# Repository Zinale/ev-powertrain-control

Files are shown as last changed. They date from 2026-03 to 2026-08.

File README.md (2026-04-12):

# MCU (Motor Control Unit) - Peacock Elettrica ⚡

This repository contains the Motor Control Unit firmware for the Polimarche Racing Team electric vehicle. It includes code for managing dual AMK inverters via CAN Bus, reading sensors via ADC with DMA, FSAE-compliant safety logic, single-pedal regenerative braking, and vehicle dynamics models in MATLAB/Simulink. The board used is the STM32 Nucleo-F756ZG.

> **Note:** This repository covers only the **MCU** and the MATLAB/Simulink vehicle dynamics models. The ECU (sensor acquisition board) has been moved to its own repository.

## Features
- ✅ **AMK Inverter Control**: Full state machine (IDLE → LV → HV → READY → RUNNING) with AMK 8.2.6 error recovery sequence and automatic retry logic.
- ✅ **Regenerative Braking**: Four-stage single-pedal regen with speed fade-out, battery power limit, and DC bus voltage derating.
- ✅ **FSAE Safety Compliance**: APPS plausibility checks (T11.8.9, T11.8.10) and MCU state machine with torque interlock.
- ✅ **ADC with DMA**: Continuous multi-channel reading (APPS1, APPS2, Steering) without CPU overhead.
- ✅ **Dual CAN Bus**: CAN1 for inverter protocol, CAN2 for vehicle telemetry (dashboard, BMS, IMU, R2D).
- ✅ **Signal Filtering**: Median + Moving Average cascade on APPS and SAS for noise rejection.
- ✅ **FreeRTOS Real-Time Architecture**: 1 kHz motor control task, 1 kHz sensor task, 10 Hz logging task.
- ✅ **Vehicle Dynamics Models**: MATLAB/Simulink models for slip control, torque vectoring, and straight-line control.

## 🔗 Repository Structure

The repository is organized into three main sections: **mcu-stm32** (STM32 firmware), **Controls** (MATLAB/Simulink models), and **Tests** (bench test infrastructure and data).

```
├── mcu-stm32/                       # STM32F756ZG firmware (main project)
│   ├── mcu-stm32.ioc                # STM32CubeMX configuration
│   └── Core/
│       ├── Inc/                     # Headers organized by subsystem
│       │   ├── Config.h             # Build modes, feature flags, parameters
│       │   ├── Communication/       # CAN bus & UART serial
│       │   ├── Drive/               # Inverter, torque control, regen, error recovery
│       │   ├── Safety/              # MCU state machine, device state, watchdog
│       │   ├── Sensors/             # ADC/DMA, APPS, steering angle
│       │   └── Tasks/               # FreeRTOS task definitions
│       └── Src/                     # Implementations (mirrors Inc/ structure)
│
├── Controls/                        # MATLAB/Simulink vehicle dynamics models
│   ├── SlipControl/                 # Traction/slip ratio control
│   ├── StraightLineControl/         # Straight-line stability
│   └── TorqueVectoring/             # Torque vectoring with 3D car model
│
├── AIPEX/                           # AMK inverter configuration files (.aipex)
│   ├── FIXED_speed/                 # Speed control mode configurations
│   ├── FREE_torque/                 # Torque control mode configurations
│   ├── Scope Templates/             # AipexPRO oscilloscope templates
│   └── Errors/                      # Error log files
│
├── Documents/                       # Datasheets, manuals, AipexPRO guides
│
├── Tests/                           # Test infrastructure & bench data
│   ├── DataCollectorSoftware/       # Python/MATLAB data logging & analysis
│   ├── ControlUnit_Nucleo_F756ZG/   # Alternative board test project
│   ├── ESP32-WIFI-BT-communication/ # Wireless telemetry via ESP32
│   ├── FeatherDataCollectorBancoMotori/ # Feather CAN data logger
│   └── FixedCan - Banco Loccioni/   # Last bench test in Speed-Control mode
│
└── Regen_Pedal_Behavior.md          # Detailed regen pedal behavior documentation
```

### MCU (Motor Control Unit)
The firmware on the STM32F756ZG manages AMK inverter control in real time:
- **Drive modules**: AMK state machine, torque control loop, error recovery, regenerative braking
- **Sensor acquisition**: DMA-based ADC reading, APPS and steering processing
- **CAN communication**: Inverter setpoints on CAN1, vehicle telemetry on CAN2
- **Safety**: MCU state machine with torque interlock, APPS plausibility, watchdog

### Controls
MATLAB/Simulink models developed to study and simulate vehicle dynamics:
- **SlipControl**: Traction/slip ratio control algorithms
- **StraightLineControl**: Straight-line torque distribution
- **TorqueVectoring**: Full torque vectoring model with 3D vehicle dynamics

### Tests
Development, bench testing, and data collection infrastructure:
- **DataCollectorSoftware**: Python CSV logger + MATLAB analysis scripts
- **ControlUnit_Nucleo_F756ZG**: Alternative MCU implementation for testing
- **ESP32-WIFI-BT-communication**: Wireless data streaming from bench
- **FixedCan - Banco Loccioni**: Last bench test configuration (Speed-Control mode, Loccioni dyno)

## 🏗️ Detailed Control Unit Structure

The control unit implementation is located in `mcu-stm32/`. The architecture follows a modular design with feature-specific subfolders. Subfolders within `Inc/` contain headers (.h), while subfolders within `Src/` provide the corresponding sources (.c).

```
└── mcu-stm32/
    ├── mcu-stm32.ioc                  # STM32CubeMX configuration file
    └── Core/
        ├── Inc/
        │   ├── Config.h               # Build modes, feature flags, all parameters
        │   ├── Communication/
        │   │   ├── Can.h              # CAN1 (inverters) + CAN2 (vehicle) TX/RX
        │   │   └── Serial.h           # DMA UART logging (UART3, UART5, UART6)
        │   ├── Drive/
        │   │   ├── Inverter.h         # AMK state machine + CAN message decode
        │   │   ├── BaseControlMotor.h # Torque control loop, rate limiting, LEDs
        │   │   ├── ErrorRecovery.h    # AMK 8.2.6 error reset state machine
        │   │   └── Regen.h            # 4-stage regenerative braking
        │   ├── Safety/
        │   │   ├── MCU_State.h        # System state machine (INIT→READY→RUNNING/ERROR)
        │   │   ├── device_state.h     # Device state tracking
        │   │   └── watchdog.h         # IWDG refresh
        │   ├── Sensors/
        │   │   ├── ADC_Manager.h      # Centralized DMA ADC handling
        │   │   ├── APPS.h             # Accelerator Pedal Position Sensors (FSAE T11.8)
        │   │   └── SAS.h              # Steering Angle Sensor with filtering
        │   └── Tasks/
        │       ├── motors_manager.h   # 1 kHz inverter control task
        │       ├── data_manager.h     # 1 kHz sensor sampling task
        │       └── data_logger.h      # 10 Hz UART/CAN2 telemetry task
        └── Src/
            ├── Communication/
            │   ├── Can.c
            │   └── Serial.c
            ├── Drive/
            │   ├── Inverter.c
            │   ├── BaseControlMotor.c
            │   ├── ErrorRecovery.c
            │   └── Regen.c
            ├── Safety/
            │   ├── MCU_State.c
            │   ├── device_state.c
            │   └── watchdog.c
            ├── Sensors/
            │   ├── ADC_Manager.c
            │   ├── APPS.c
            │   └── SAS.c
            ├── Tasks/
            │   ├── motors_manager.c
            │   ├── data_manager.c
            │   └── data_logger.c
            └── main.c
```

## 🧪 Build Modes & Testing

The project supports different build modes configured in `Config.h`. This allows testing with limited hardware availability.

### Test Mode: Single ADC (`TEST_MODE_SINGLE_ADC`)
Enable when only **ADC1 CH0 (PA0)** is available:

```c
// In Config.h — uncomment to enable:
#define TEST_MODE_SINGLE_ADC
```

**Effects:**
- Uses only 1 ADC channel instead of 3
- APPS sensor 2 is simulated (duplicates sensor 1 value)
- Sensor mismatch plausibility check **disabled** (can't verify with 1 sensor)
- Range check **disabled**
- Deadzone 30% still active for realistic pedal behavior

### Test Mode: Full (`TEST_MODE_FULL`)
Enable for bench testing with all ADC channels but relaxed safety thresholds:

```c
// In Config.h — uncomment to enable:
#define TEST_MODE_FULL
```

**Effects:**
- All 3 ADC channels active (APPS1, APPS2, Steering)
- Implausibility threshold relaxed to 20% (instead of 10%)
- Implausibility timeout extended to 500 ms (instead of 100 ms)

### Production Mode (`RELEASE_MODE`)
Comment out all test modes for full FSAE compliance:

```c
// In Config.h — comment out all test modes:
//#define TEST_MODE_SINGLE_ADC
//#define TEST_MODE_FULL
#define RELEASE_MODE
```

**Effects:**
- All 3 ADC channels active
- Full APPS plausibility check: mismatch >10% for >100 ms → shutdown
- Full range check (open/short circuit detection)
- Deadzone 30% active
- All FSAE safety rules enforced

## 🎮 Module Descriptions

### APPS (Accelerator Pedal Position Sensors)
Located in `Sensors/APPS.h` and `Sensors/APPS.c`:
- **Dual sensor reading**: Two redundant potentiometers with independent transfer functions
- **Signal filtering**: Median filter (11 samples) + Moving Average (40 samples) cascade
- **Normalization**: Converts raw ADC values to 0–100% pedal position
- **FSAE Plausibility checks**:
  - **T11.8.9**: Sensor mismatch >10% for >100 ms → motor shutdown
  - **T11.8.10**: Auto-reset when pedal returns below 5%
  - **Out-of-range detection**: Open/short circuit with ADC bounds checking

### ADC Manager
Located in `Sensors/ADC_Manager.h` and `Sensors/ADC_Manager.c`:
- **DMA circular mode**: Continuous multi-channel ADC without CPU intervention
- **Thread-safe access**: Getter functions for other modules
- **Channels**: APPS1 (PA0), APPS2 (PA1), Steering (PC3)

### Inverter Control
Located in `Drive/Inverter.h` and `Drive/Inverter.c`:
- **AMK state machine**: IDLE → LV_ACTIVE → HV_ACTIVE → READY → RUNNING
- **CAN message decoding**: Status words (SM1–SM5), speed, torque, temperatures, power
- **AMK protocol**: Control word bits for enable, DC activation, error reset

### Error Recovery
Located in `Drive/ErrorRecovery.h` and `Drive/ErrorRecovery.c`:
- **AMK 8.2.6 sequence**: `bInverterOn=0` → `bErrorReset=1` (50 ms hold) → `bErrorReset=0` (falling edge triggers reset)
- **Retry logic**: Up to 5 automatic recovery attempts with 100 ms cooldown between tries
- **Per-inverter context**: Independent recovery state for each motor node

### Base Control Motor
Located in `Drive/BaseControlMotor.h` and `Drive/BaseControlMotor.c`:
- **Dynamic torque limiting**: AMK formula based on speed and DC bus voltage (`M = P / (2π × N/60)`)
- **Rate limiting**: Smooth torque transitions (10 units per ms)
- **Status LED management**: Visual feedback for error and running states

### Regenerative Braking
Located in `Drive/Regen.h` and `Drive/Regen.c`:
- **4-stage calculation**: Pedal-dependent → speed fade-out → battery power limit → DC bus derating
- **Latch hysteresis**: Entry/exit thresholds to prevent regen chattering at low speed
- **Configurable intensity**: CONSERVATIVE / BALANCED / AGGRESSIVE modes in `Config.h`

### CAN Communication
Located in `Communication/Can.h` and `Communication/Can.c`:
- **CAN1**: Inverter protocol — setpoints TX at 1 kHz, status RX at 1 kHz
- **CAN2**: Vehicle telemetry — BMS, IMU, R2D RX; error snapshots and sensor data TX
- **Hardware**: SN65HVD230 CAN transceiver (×2)

### Serial Communication
Located in `Communication/Serial.h` and `Communication/Serial.c`:
- **DMA-based transmission**: Non-blocking TX on UART3, UART5, UART6
- **Per-channel enable**: Each UART can be independently enabled/disabled in `Config.h`
- **Mutex-protected**: Thread-safe printf-style logging from FreeRTOS tasks

## ⏱️ FreeRTOS Task Architecture

The system uses FreeRTOS with three dedicated tasks. All shared data is protected via FreeRTOS mutexes.

### Task Overview

| Task | Period  | Responsible for |
|---|---|---|
| `MotorsManagerTask` | 10 ms  | Inverter state machine, torque command, error recovery, regen |
| `DataManagerTask`  | 4 ms | ADC reading, APPS/SAS processing, sensor filtering |
| `DataLoggerTask` | 100 ms  | UART serial output and CAN2 telemetry |

### Motors Manager Task (10 ms)
The core control loop executed every 10 ms:

```c
void MotorsManagerTask(void *argument)
{
    for (;;)
    {
        // 1. Read sensor data (pedal %, steering %)
        // 2. For each inverter:
        //    a. Decode CAN status (Inverter_ProcessReceivedMessage)
        //    b. Run state machine + error recovery (Motor_ProcessInverterControl)
        //    c. If RUNNING: compute torque setpoint with regen + rate limit
        //    d. Send CAN command (Inverter_BuildCommand + Can_SendInverterCommand)
        osDelay(INVERTERS_TASK_PERIOD_MS);
    }
}
```

### Data Manager Task (4 ms)
Runs ADC acquisition and sensor processing every 1 ms:

```c
void DataManagerTask(void *argument)
{
    for (;;)
    {
        // 1. Read DMA ADC buffer (ADC_Manager_GetValues)
        // 2. Process APPS (APPS_Process) — filtering + plausibility
        // 3. Process SAS  (SAS_Process)  — filtering + normalization
        // 4. Update MCU state machine
        osDelay(1);
    }
}
```

### Data Logger Task (100 ms)
Outputs diagnostics and telemetry every 100 ms:

```c
void DataLoggerTask(void *argument)
{
    for (;;)
    {
        // 1. Log inverter data via UART (Serial_Log)
        // 2. Transmit CAN2 telemetry messages (APPS%, steering%, inverter data, errors)
        osDelay(100);
    }
}
```

## 🛠️ Commands & Installation

### MCU Control Unit (STM32)

1. **Clone the repository**:
   ```bash
   git clone https://github.com/PolimarcheRacingTeam/ev-powertrain-control.git
   ```
2. **Open the project with STM32CubeIDE**
3. **Navigate to `mcu-stm32/`** (the main firmware project)
4. **Select build mode** in `Core/Inc/Config.h` (see Build Modes section)
5. **Compile and upload** to the Nucleo-F756ZG board
6. **Monitor serial output** at 115200 baud (e.g., using Termite or PuTTY on UART3)

### AMK Inverter Configuration (AIPEX)

1. **Install AipexPRO** (refer to `Documents/AipexPRO/`)
2. **Load configuration** from `AIPEX/FREE_torque/` (torque control) or `AIPEX/FIXED_speed/` (speed control)
3. **Connect to AMK inverter** via CAN bus
4. **Use scope templates** from `AIPEX/Scope Templates/` for live monitoring

### Data Collection (Bench / Tests)

1. **Navigate to `Tests/DataCollectorSoftware/`**
2. **Run the Python logger** `csv_socket_logger.py` — streams CSV data from ESP32 over Wi-Fi
3. **Analyze data** using `analyze_test_log.m` in MATLAB

## 🔧 Hardware Configuration

### STM32F756ZG Peripherals
(see `mcu-stm32/mcu-stm32.ioc` for full CubeMX configuration)

- **ADC1**: 3-channel DMA circular mode — APPS1 (PA0), APPS2 (PA1), Steering (PC3)
- **CAN1**: Inverter communication at 1 Mbit/s (SN65HVD230 transceiver)
- **CAN2**: Vehicle telemetry at 500 kbit/s (SN65HVD230 transceiver)
- **UART3**: PC debug serial at 115200 baud (DMA TX)
- **UART5**: Data logger / ESP32 at 115200 baud (DMA TX)
- **UART6**: External device (DMA TX)
- **GPIO**: LD2 (green), LD3 (red) status LEDs; R2D signal input

### CAN Bus Hardware
- **Transceiver**: SN65HVD230 (3.3 V compatible), ×2 for CAN1 + CAN2
- **Baud Rates**: CAN1 @ 1 Mbit/s (AMK inverter), CAN2 @ 500 kbit/s (vehicle)
- **Termination**: 120 Ω at both ends of each bus

### AMK Motor & Inverter
- **Motor**: AMK DD series — 9.8 Nm nominal, 21 Nm peak, 16000 RPM max
- **Inverter**: AMK KW-R25 — CAN-based torque control
- **CAN node IDs**: Right inverter = 1 (0x184/0x284), Left inverter = 2 (0x185/0x285)

## 🏎️ FSAE Rules Compliance

### APPS Plausibility (T11.8.9)
- Dual redundant sensors with independent transfer functions
- If sensor mismatch exceeds 10% for more than 100 ms → motor power immediately cut
- Configurable in `APPS.h`:
  ```c
  #define APPS_IMPLAUSIBILITY_THRESHOLD_PERCENT   10U   // Difference threshold [%]
  #define APPS_IMPLAUSIBILITY_TIMEOUT_MS          100U  // Time before failure [ms]
  ```

### APPS Reset (T11.8.10)
- After an implausibility event, torque cannot be restored until the pedal returns below 5%
- Prevents unintended torque restoration after driver removes foot

### Out-of-Range Detection (EV.4.7)
- Each ADC channel checked for open-circuit (value too low) and short-circuit (value too high)
- Detection uses configurable ADC margin counts
- Fault triggers shutdown independently from plausibility check

## 📚 Documentation References

### Internal Documentation
- **AMK Inverter**: `Documents/` — AipexPRO guides, training materials, password info
- **Regen behavior**: `Regen_Pedal_Behavior.md` — full pedal-speed regen interaction map
- **MCU Configuration**: `mcu-stm32/mcu-stm32.ioc` — STM32CubeMX project configuration

### FSAE Rules Reference
- **Formula SAE Rules**: [FSAE Online](https://www.fsaeonline.com/)
- **T11.8.9 / T11.8.10**: APPS sensor plausibility and reset conditions
- **EV.4.7**: Accelerator pedal position sensor requirements

### External Resources

- **NUCLEO F756ZG**:  
  📄 [Pinout](https://os.mbed.com/platforms/ST-Nucleo-F756ZG/)

- **SN65HVD230 CAN Transceiver**:  
  🎞️ [Video Tutorial 1](https://youtu.be/KHNRftBa1Vc?si=2C673-Au-6wTgh2l)  
  🎞️ [Video Tutorial 2](https://www.youtube.com/watch?v=-lcrrRrKdFg)

- **STM32 ADC with DMA**:  
  🎞️ [Video Tutorial](https://www.youtube.com/watch?v=zipjCtiHYr8)  
  📄 [In-depth Guide](https://deepbluembedded.com/stm32-adc-multi-channel-scan-continuous-mode-dma-poll-examples/)

- **AMK Motor & Inverter**:  
  📄 [AipexPRO Documentation](Documents/AipexPRO/)

## 👥 Authors

- **Alessandro Zingaretti** — *Polimarche Racing Team, UNIVPM*

## 👀 Interested in Learning More?

If you have any questions, would like to discuss this project further, or are interested in potential collaboration opportunities, please feel free to connect with us:

- LinkedIn: [polimarcheracingteam](https://www.linkedin.com/company/polimarcheracingteam/posts/?feedView=all)
- Instagram: [polimarcheracingteam](https://www.instagram.com/polimarcheracingteam/)
- Email: [formulasae@sm.univpm.it](mailto:formulasae@sm.univpm.it)

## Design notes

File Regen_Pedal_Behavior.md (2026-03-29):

# Regen — Comportamento Pedale nelle varie condizioni

> Configurazione: `DEADZONE=25%`, `REGEN_THRESHOLD=25%`, `HYST=±3%`, `MODE=CONSERVATIVE (4.9 Nm max)`, `SPEED_MIN=3000 RPM`, `SPEED_CRITICAL=2000 RPM`

## Pedale fisico → `final_percent`

| Pedale fisico | `final_percent` |
|:---:|:---:|
| 0-25% | 0% (deadzone) |
| 25-100% | 0-100% (lineare) |

---

## Comportamento per condizione di velocità

### 🔴 Velocità < 2000 RPM — **Solo trazione**
Regen **impossibile** (latch forzatamente OFF).

| `final_pct` | Coppia |
|:---:|:---|
| 0% | 0 Nm (coasting) |
| 50% | +10.3 Nm |
| 100% | +20.6 Nm |

---

### 🟡 Velocità 2000-3000 RPM — **Trazione + regen solo se già attiva**
Non puoi **entrare** in regen, ma se eri già in regen (latch ON da prima) ci resti con fade-out.

| `final_pct` | Se latch OFF (trazione) | Se latch ON (regen) |
|:---:|:---|:---|
| 0% | 0 Nm (coasting) | -4.9 × k_vel Nm (fade-out) |
| 22% | +4.6 Nm | -0.6 × k_vel Nm |
| 28% | +5.8 Nm | latch OFF → +5.8 Nm |
| 100% | +20.6 Nm | — |

*k_vel = speed / 3000 (es. a 2500 RPM → k_vel = 0.83)*

---

### 🟢 Velocità > 3000 RPM — **Trazione + regen completa**
Puoi **entrare** in regen. Coppia regen al 100%.

| `final_pct` | Modo | Coppia |
|:---:|:---:|:---|
| 0% | **REGEN** | **-4.9 Nm** (100% regen conservative) |
| 12.5% | REGEN | -2.45 Nm |
| 22% | LATCH border | -0.6 Nm (regen) o +4.6 Nm (trazione) |
| 22-28% | LATCH band | Mantiene modo precedente |
| 28% | **TRACTION** | +5.8 Nm |
| 50% | TRACTION | +10.3 Nm |
| 100% | TRACTION | **+20.6 Nm** |

---

### Protezione aggiuntiva
| Condizione | Coppia |
|:---|:---:|
| speed < 10 RPM | **0 Nm** |
| speed > 16000 RPM | **0 Nm** |
| DC bus > 380V | Regen derata |
| DC bus > 395V | Regen = 0 |

---

## Schema riassuntivo completo

```
                    < 2000 RPM        2000-3000 RPM       > 3000 RPM
                 ┌──────────────┬──────────────────┬──────────────────┐
  Pedale 0%      │  0 Nm coast  │ -4.9×k Nm (se    │  -4.9 Nm         │
  (rilasciato)   │              │  già in regen)    │  REGEN PIENA     │
                 │              │ 0 Nm (se no)      │                  │
  ───────────────┼──────────────┼──────────────────┼──────────────────┤
  Pedale 22%     │  +4.6 Nm     │ dipende dal latch │ dipende dal latch│
  (latch enter)  │  trazione    │                  │                  │
  ───────────────┼──────────────┼──────────────────┼──────────────────┤
  Pedale 28%     │  +5.8 Nm     │  +5.8 Nm         │  +5.8 Nm         │
  (latch exit)   │  trazione    │  TRAZIONE         │  TRAZIONE        │
  ───────────────┼──────────────┼──────────────────┼──────────────────┤
  Pedale 100%    │  +20.6 Nm    │  +20.6 Nm        │  +20.6 Nm        │
  (pieno)        │  trazione    │  TRAZIONE         │  TRAZIONE        │
                 └──────────────┴──────────────────┴──────────────────┘
```

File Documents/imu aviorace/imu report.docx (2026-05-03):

Testing IMU Aviorace

Introduzione

Il presente documento riporta i risultati delle prove eseguite sull'Inertial Measurement Unit (IMU) installato sulla nostra vettura prodotto da Aviorace. L'obiettivo delle prove era di verificare la corretta funzionalità dell'IMU e di identificare eventuali problemi di ricezione CAN o di alimentazione.

Descrizione delle prove

Le prove sono state eseguite in due fasi:

1. Prima accensione: l'IMU è stato acceso per la prima volta con una tensione di alimentazione di 12 V e una corrente di 20 mA. In questa fase, l'IMU non ha funzionato correttamente.
2. Seconda accensione: dopo aver consultato l'ufficio tecnico di Aviorace, è stato stabilito che la corrente richiesta dall'IMU era di 120 mA. Pertanto, l'IMU è stato acceso nuovamente con una tensione di alimentazione di 12 V e una corrente di 120 mA.

IMMAGINI SETUP PROVA DA BANCO

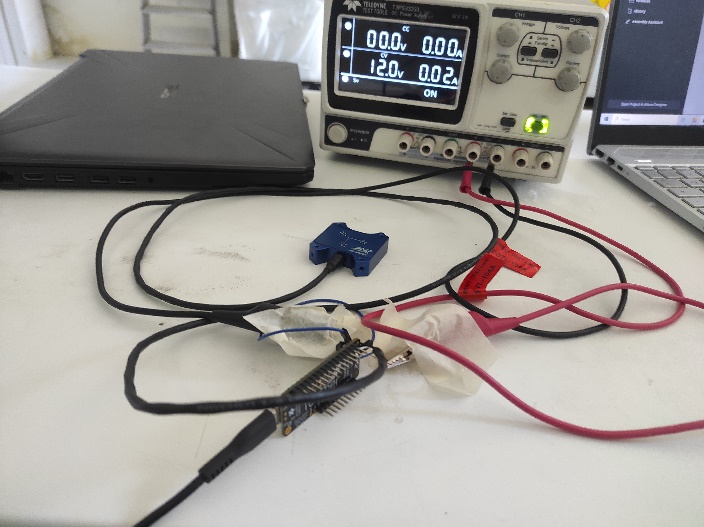
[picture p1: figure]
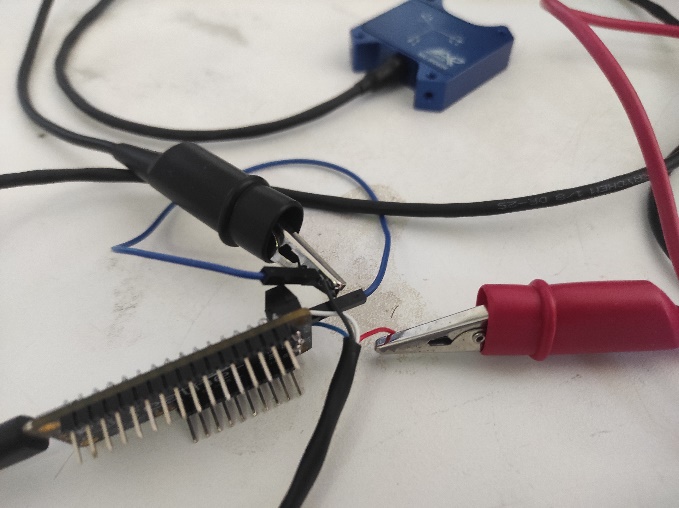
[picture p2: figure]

Risultati delle prove

I risultati delle prove sono riportati nella seguente tabella:

Parametro | Valore
Tensione di alimentazione | 12 V
Corrente assorbita | 20-30 mA
Corrente richiesta ( da inserire sul generatore) | 120 mA

Dai risultati delle prove, si evince che l'IMU richiede una corrente di 120 mA per funzionare correttamente, mentre la corrente assorbita è di 20-30 mA.

Configurazione dell'IMU

Inoltre, è stato stabilito che l'IMU può inviare valori anche senza la necessità di inviare messaggi CAN. Tuttavia, abbiamo deciso di inviare un ID CAN per impostare diversi valori.

REPROGRAM CAN ID:

Byte 0: 0x01 | DEFAULT
Byte 1: 0xAO | DEFAULT
Byte2: 0x01 | DEFAULT
Byte3: 0x02 (ACC RANGE) | 12G
Byte4:0x01 (GYRO RANGE) | DEAFULT- 250 deg/s
Byte5:0x01 (BAUD RATE) | 500kbit/s
Byte6:0x00 | CAN HI
Byte7:0x00 | CAN LO

POSITIONING CAN ID:

Byte 0: 0x01 | DEFAULT
Byte 1: 0XA3 | DEFAULT
Byte2: 0xAA | DEFAULT
Byte3: 0xAA | DEFAULT
Byte4:0xAA | DEAFULT
Byte5:0x00 | VEDI MOUNTING
Byte6: 0x01 Acc frequency 3dB | 19hz -DEFAULT
Byte 7: 0x01 Gyro frequency 3dB | 32 hz

ZERO OFFSET CAN ID:

Byte 0: 0x01 | DEFAULT
Byte 1: 0XA1 | DEFAULT
Byte2: 0xAA | DEFAULT
Byte3: 0xAA | DEFAULT
Byte4:0xAA | DEFAULT
Byte5:0xAA | DEFAULT
Byte6:0xAA | DEFAULT
Byte7:0xAA | DEFAULT

Conclusioni

In conclusione, le prove eseguite sull'IMU hanno evidenziato la necessità di una corrente di 120 mA per la sua corretta funzionalità. La configurazione dell'IMU è stata aggiornata di conseguenza. Ulteriori prove saranno eseguite per verificare la corretta ricezione dei valori dell’IMU.

Raccomandazioni

Si raccomanda di verificare regolarmente la corrente assorbita dall'IMU per garantire la sua corretta funzionalità. Inoltre, si consiglia di eseguire ulteriori prove per ottimizzare la configurazione dell'IMU e migliorare la sua precisione.

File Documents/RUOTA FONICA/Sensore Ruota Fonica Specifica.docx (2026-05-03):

Product Requirements Document

# SVH hall effect speed sensor

Issued by | Role/Department | Date
Chiara Facchini | Electronics Division Leader | 24/10/2025

# GENERAL PRODUCT DESCRIPTION

Product Description
Key Features/ Functionality | Hall-effect speed sensor, ideal for measuring the speed of bolts and tone wheels
Working conditions | Content in the phonic wheel Operating temperature: -30°C ÷ +110°C Degree of Protection: IP67 CNC-machined anodized aluminum body for excellent mechanical resistance to impacts.
Rules | No
Dimensions and Tolerances | Cfr. Rendering section
Weight | ≈ 26 g
Produzione | Aviorace SRL

# REGULATORY

Regulatory Requirements
Safety
Structural
Electrical

# DESIGN

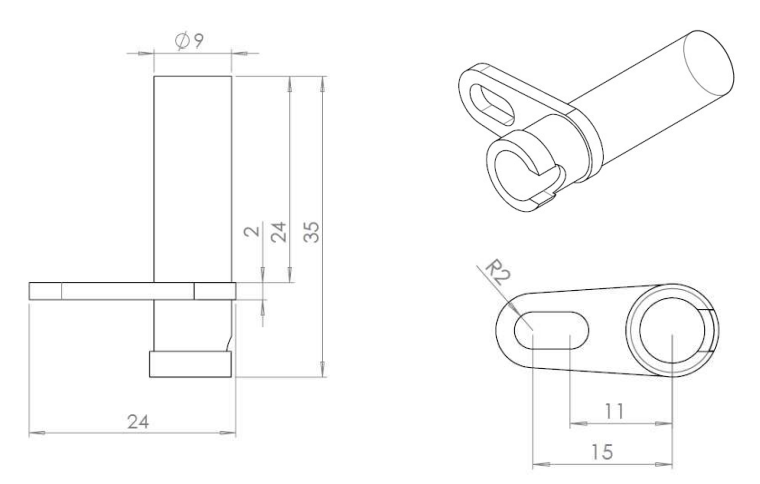
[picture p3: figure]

Renderings

# ENVIRONMENT

Operating Environment
Where in the car | Front structure
Temperature Range | -30°C ÷ +110°C

# ELECTRICAL HARDWARE AND SENSORS

Supply Voltage | 5 ÷ 18 Vdc
Supply Current | Maximum output current: 25 mA Current consumption at 12 VDC: < 20 mA
Input/Sensor Requirements | https://aviorace.com/wp-content/uploads/2021/01/SVH-rev6.pdf

# BOM

Bill of material
BOM

Financials
BOM Cost

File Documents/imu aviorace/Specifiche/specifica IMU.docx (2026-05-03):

Product Requirements Document

IMU

Issued by | Role/Department | Date
Lorenzo Meloccaro | Electronics Team Member | 01/10/2025

# GENERAL PRODUCT DESCRIPTION

Product Description
Key Features/ Functionality | The Inertial Measurement Unit (IMU) should read accelerations and angles during car’s motion sending Via CAN Bus reading of accelerometer, gyroscope and magnetometer
Software | n.a.
Other components Compatibility, Ecosystem, etc. | CanBus
Working conditions | Ip60
Rules | n.a.
Dimensions and Tolerances | 44x42x11 cm
Weight | 60 g ca
Produzione | Aviorace
Connections | Connected via CanBus to the MCU

# DESIGN

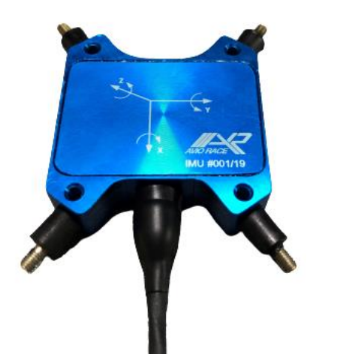
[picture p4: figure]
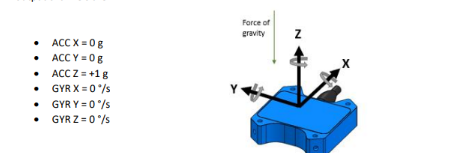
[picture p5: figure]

Renderings

# INTERFACE

Communication protocol | CanBus
Communication Input | N.a.
Communication output | CanBus
Connector | N.a.

# ELECTRICAL HARDWARE AND SENSORS

Supply Voltage | 8-16 V
Supply Current | 20 mA
Input/Sensor Requirements | N.a.
Output/Actuator Requirements | Ax,Ay,Az Gx, Gy,Gz Mx, My, Mz
OverVoltage/ OverCurrent / Short Circuit Protection on power supply | N.a.
OverVoltage/ OverCurrent / Short Circuit Protection on output | Max 50 mA

# BOM

Bill of material
BOM

Financials
BOM Cost

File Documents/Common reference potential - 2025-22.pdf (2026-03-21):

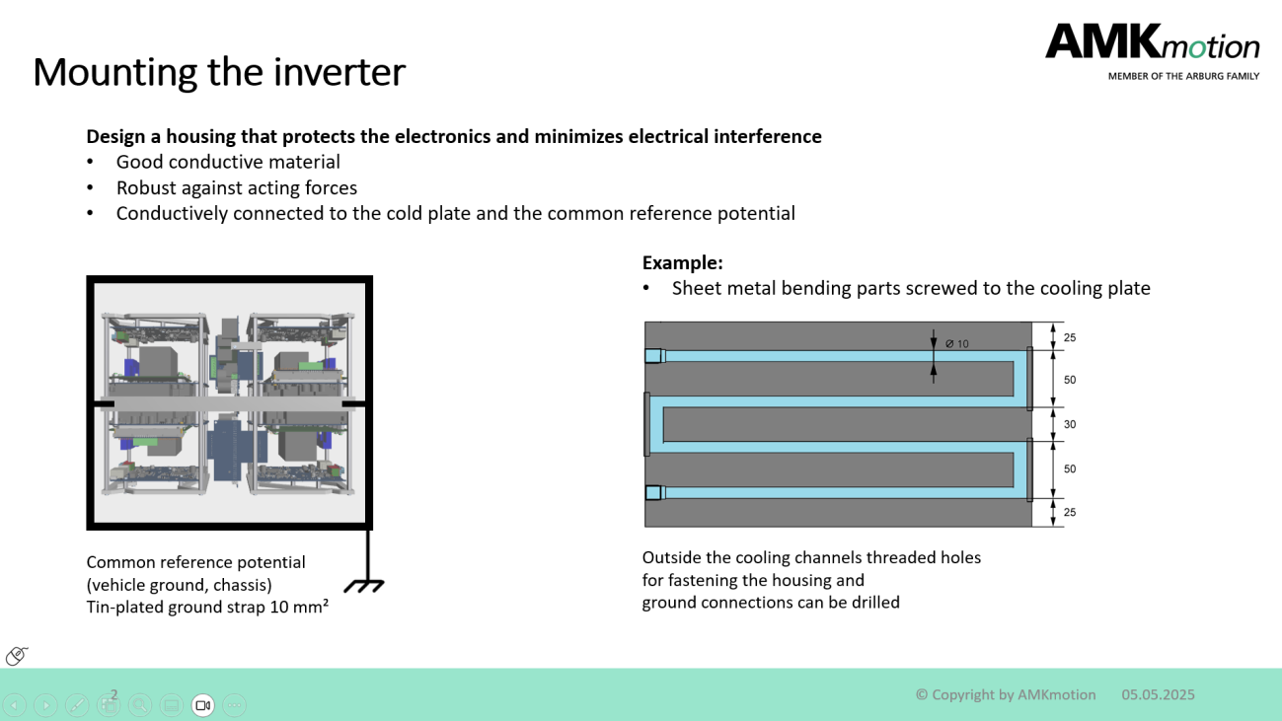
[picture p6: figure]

Common reference potential - 2025-22 | Rev:01/26.05.2025 | Seite 1 von 4
26.05.2025

Common reference potential (Shielding and Grounding)

Motor / Inverter
In the case of high-frequency interference, it is not the cross-section of the wire important, but the surface (because of skin effect).
Use a tin-plated ground strap with 10 mm²

Motor
Connect each motor separately to the common reference potential.

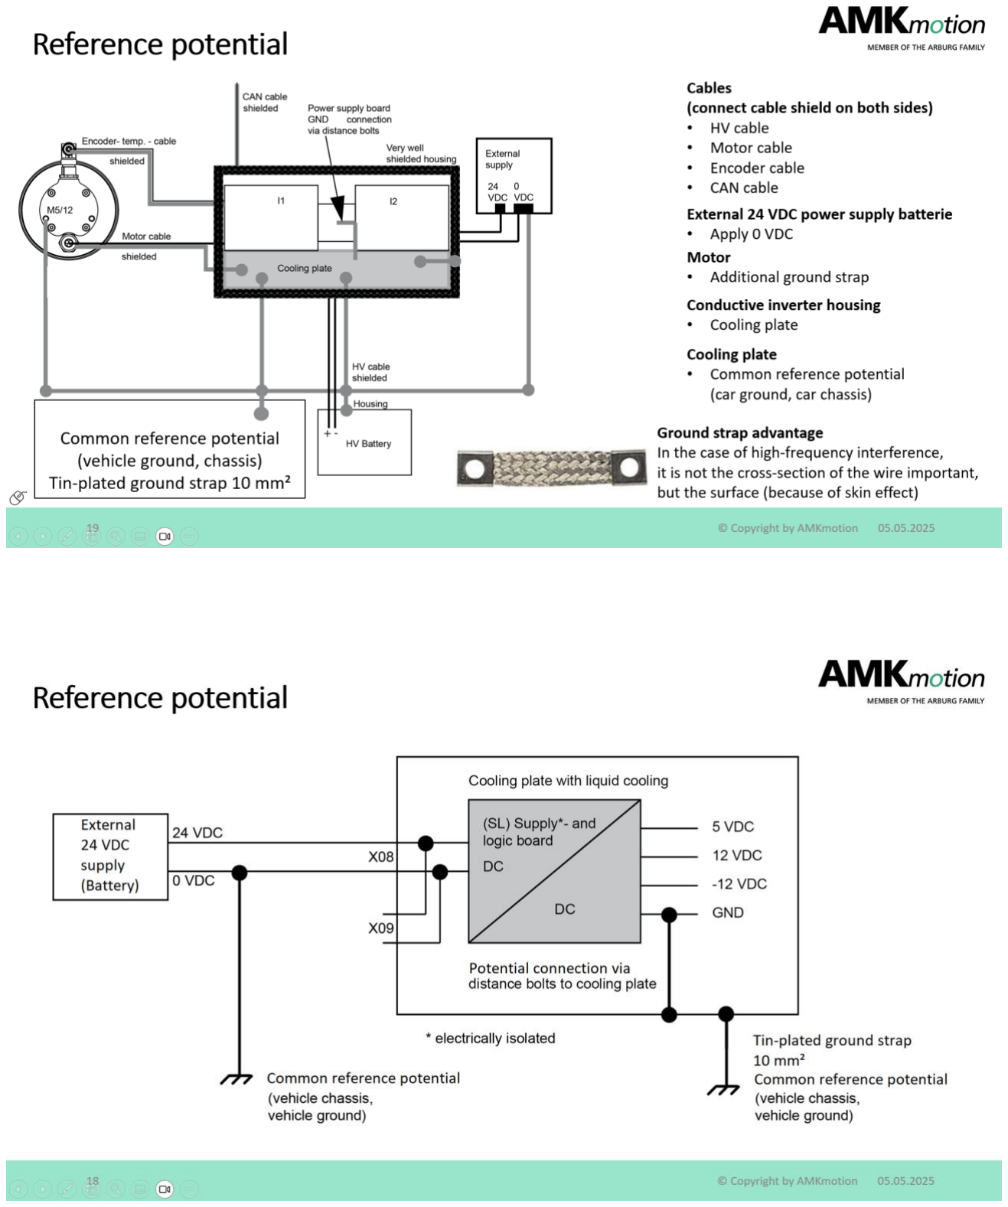
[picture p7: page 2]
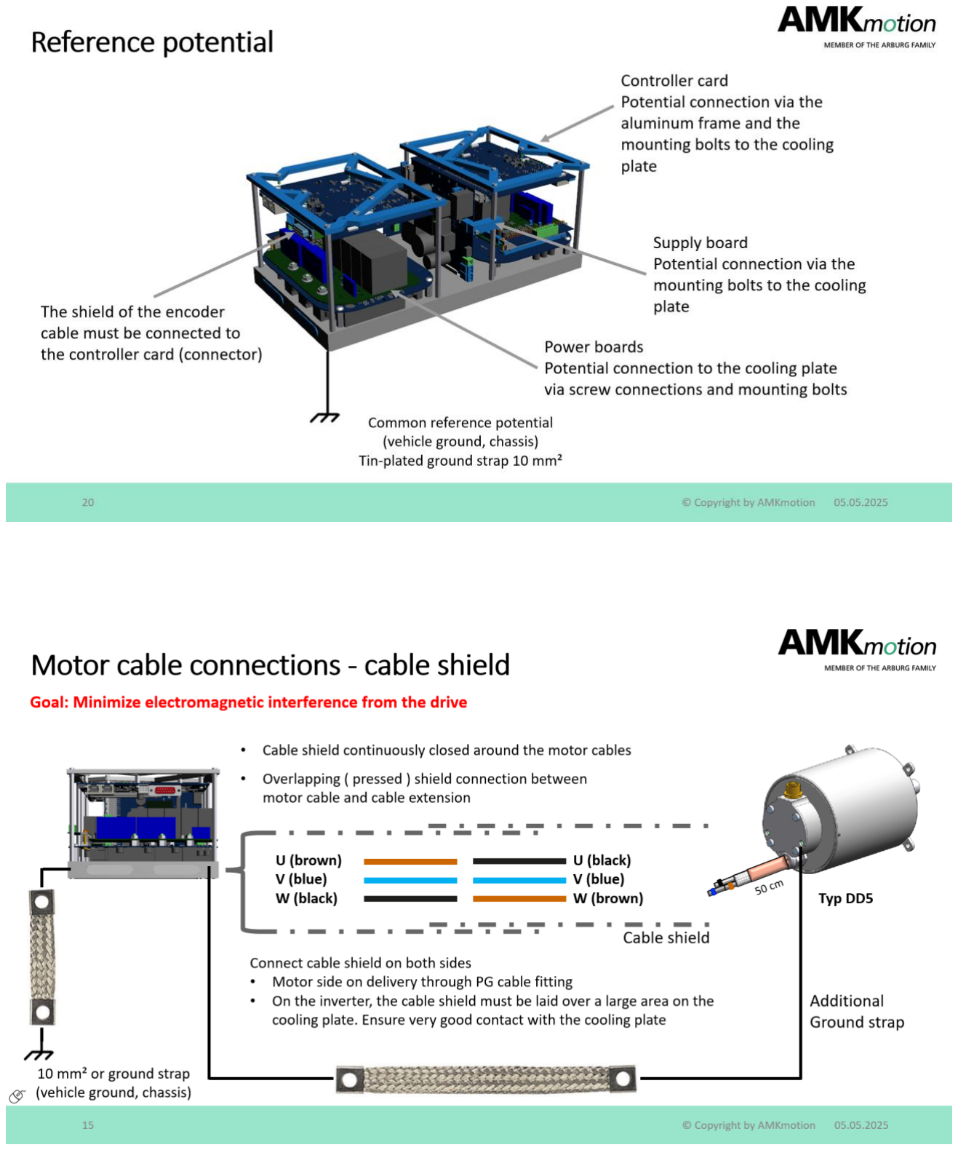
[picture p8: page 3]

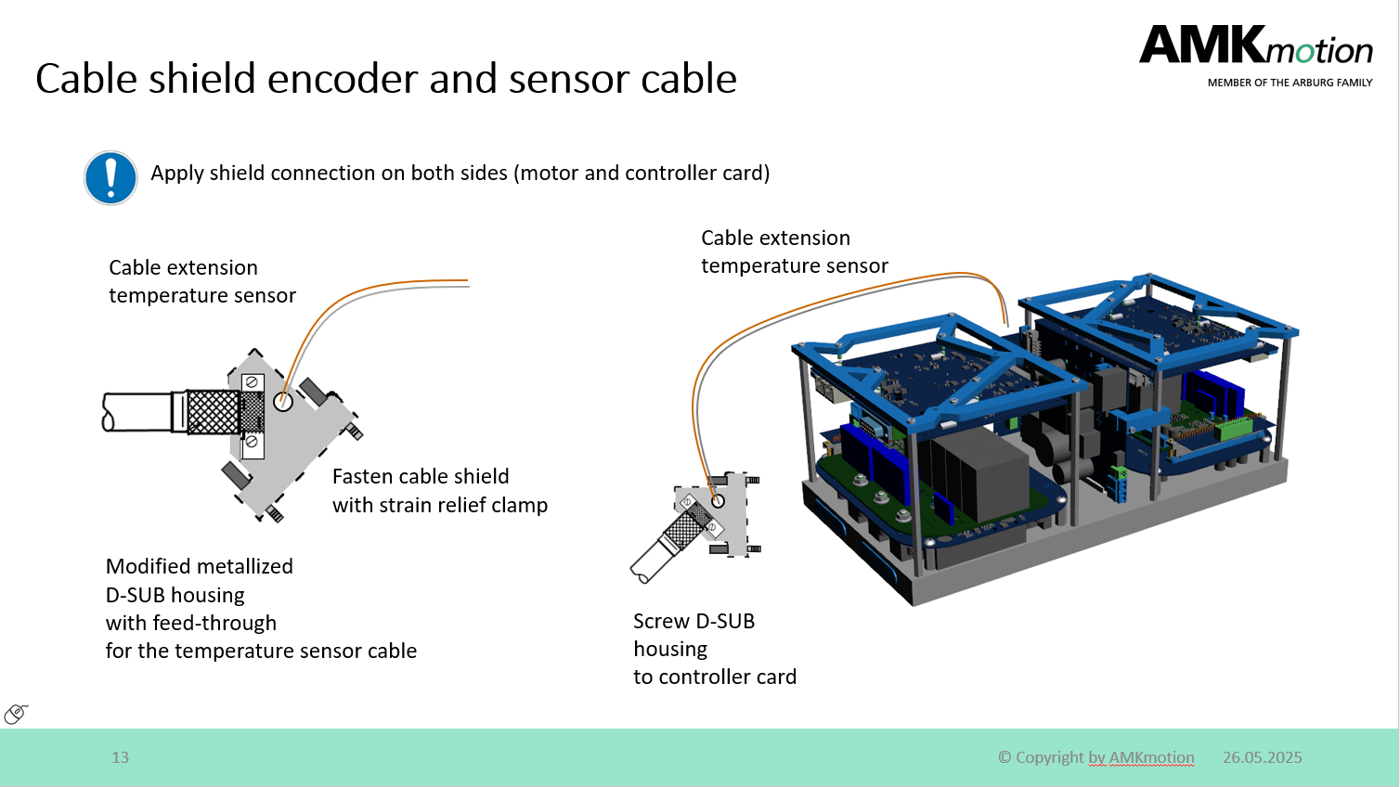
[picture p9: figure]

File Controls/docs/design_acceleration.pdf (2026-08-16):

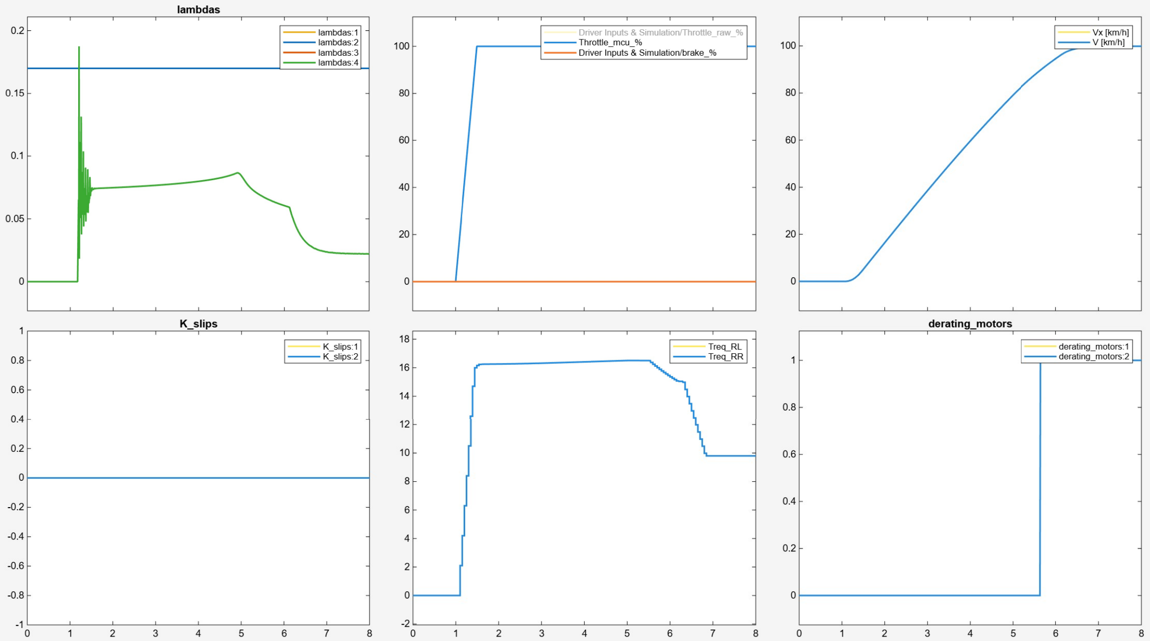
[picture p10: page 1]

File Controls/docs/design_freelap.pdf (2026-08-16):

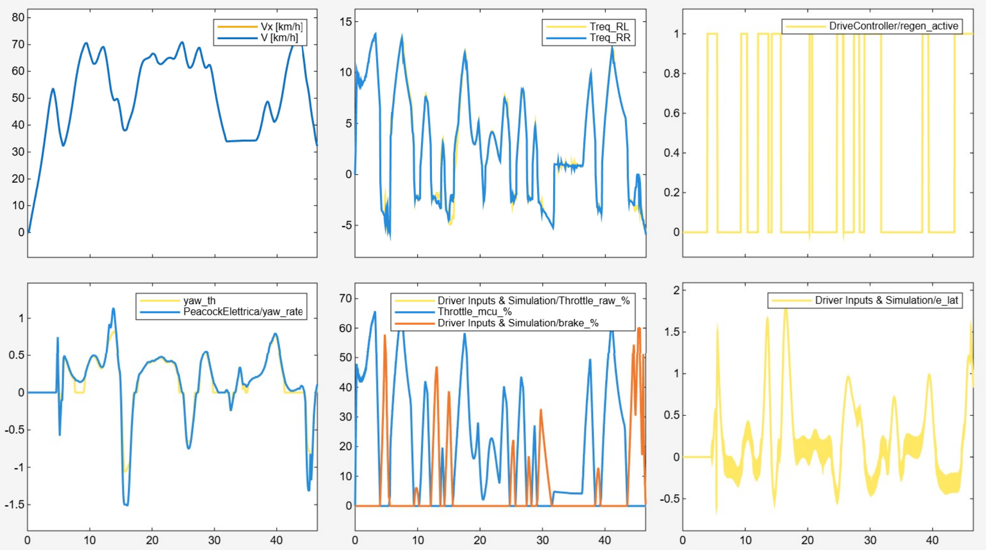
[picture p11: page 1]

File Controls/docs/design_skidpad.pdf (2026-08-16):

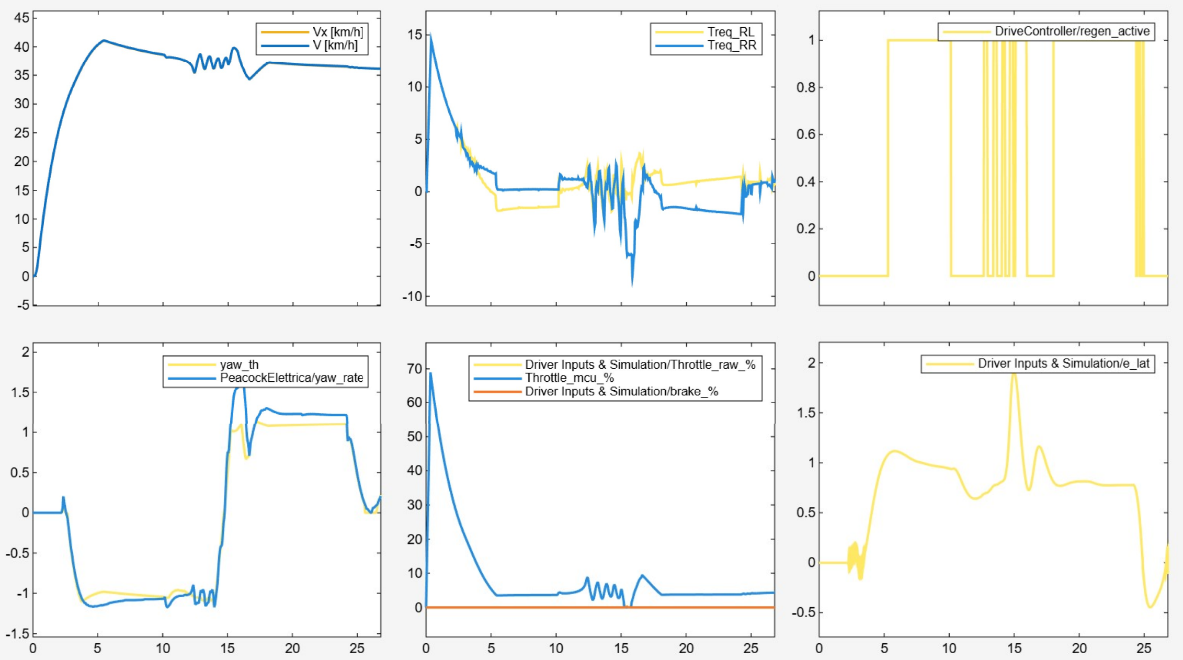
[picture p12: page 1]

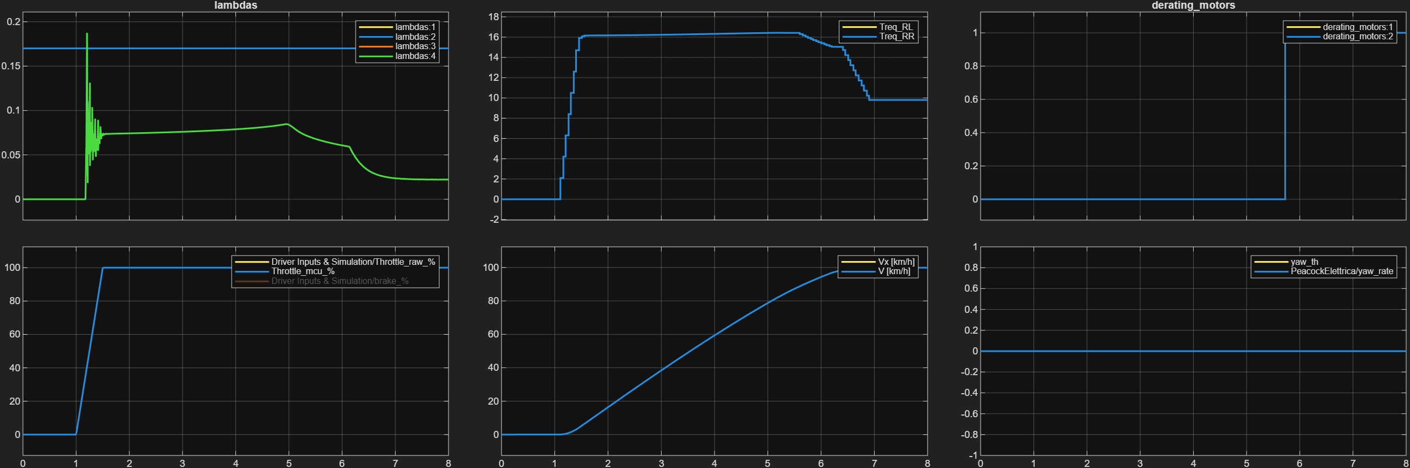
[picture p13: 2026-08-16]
Controls/docs/design_acceleration.png

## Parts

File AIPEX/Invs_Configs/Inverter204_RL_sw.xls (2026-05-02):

Id | Name | P-Set | Value | Unit | Remark
1 | NC cycle time | 0 | 1.000 | ms
2 | SERCOS cycle time | 0 | 1.000 | ms
6 | Drive telegr.start.time | 0 | 0.200 | ms
7 | Feedb.acquis.start.time | 0 | 0.000 | ms
8 | Command valid time (T3) | 0 | 0.000 | ms
11 | Status class 1-errors | 0 | 0000 0000 0000 0000B
12 | Status class 2-warnings | 0 | 0000 0000 0000 0000B
13 | Status class 3-messages | 0 | 0000 0000 0000 0000B
15 | Telegr. type par. | 0 | 6
16 | Configuration list AT | 0 | 0
17 | ID-No.list all op.data | 0 | 529
17-2 |  | 0 | 1
17-3 |  | 0 | 2
17-4 |  | 0 | 6
17-5 |  | 0 | 7
17-6 |  | 0 | 8
17-7 |  | 0 | 11
17-8 |  | 0 | 12
17-9 |  | 0 | 13
17-10 |  | 0 | 15
17-11 |  | 0 | 16
17-12 |  | 0 | 17
17-13 |  | 0 | 18
17-14 |  | 0 | 19
17-15 |  | 0 | 20
17-16 |  | 0 | 21
17-17 |  | 0 | 22
17-18 |  | 0 | 23
17-19 |  | 0 | 24
17-20 |  | 0 | 25
17-21 |  | 0 | 26
17-22 |  | 0 | 28
17-23 |  | 0 | 29
17-24 |  | 0 | 30
17-25 |  | 0 | 32
17-26 |  | 0 | 33
17-27 |  | 0 | 34
17-28 |  | 0 | 35
17-29 |  | 0 | 36
17-30 |  | 0 | 37
17-31 |  | 0 | 38
17-32 |  | 0 | 39
17-33 |  | 0 | 40
17-34 |  | 0 | 41
17-35 |  | 0 | 42
17-36 |  | 0 | 43
17-37 |  | 0 | 44
17-38 |  | 0 | 45
17-39 |  | 0 | 46
17-40 |  | 0 | 47
17-41 |  | 0 | 49
17-42 |  | 0 | 50
17-43 |  | 0 | 51
17-44 |  | 0 | 52
17-45 |  | 0 | 55
17-46 |  | 0 | 57
17-47 |  | 0 | 76
17-48 |  | 0 | 77
17-49 |  | 0 | 78
17-50 |  | 0 | 79
17-51 |  | 0 | 80
17-52 |  | 0 | 81
17-53 |  | 0 | 82
17-54 |  | 0 | 83
17-55 |  | 0 | 84
17-56 |  | 0 | 85
17-57 |  | 0 | 86
17-58 |  | 0 | 89
17-59 |  | 0 | 91
17-60 |  | 0 | 92
17-61 |  | 0 | 93
17-62 |  | 0 | 94
17-63 |  | 0 | 95
17-64 |  | 0 | 96
17-65 |  | 0 | 97
17-66 |  | 0 | 98
17-67 |  | 0 | 99
17-68 |  | 0 | 100
17-69 |  | 0 | 101
17-70 |  | 0 | 102
17-71 |  | 0 | 103
17-72 |  | 0 | 104
17-73 |  | 0 | 108
17-74 |  | 0 | 109
17-75 |  | 0 | 110
17-76 |  | 0 | 111
17-77 |  | 0 | 112
17-78 |  | 0 | 113
17-79 |  | 0 | 114
17-80 |  | 0 | 115
17-81 |  | 0 | 116
17-82 |  | 0 | 117
17-83 |  | 0 | 121
17-84 |  | 0 | 122
17-85 |  | 0 | 123
17-86 |  | 0 | 124
17-87 |  | 0 | 125
17-88 |  | 0 | 126
17-89 |  | 0 | 129
17-90 |  | 0 | 130
17-91 |  | 0 | 131
17-92 |  | 0 | 132
17-93 |  | 0 | 133
17-94 |  | 0 | 134
17-95 |  | 0 | 135
17-96 |  | 0 | 136
17-97 |  | 0 | 137
17-98 |  | 0 | 140
17-99 |  | 0 | 141
17-100 |  | 0 | 142
17-101 |  | 0 | 143
17-102 |  | 0 | 144
17-103 |  | 0 | 147
17-104 |  | 0 | 148
17-105 |  | 0 | 149
17-106 |  | 0 | 150
17-107 |  | 0 | 153
17-108 |  | 0 | 154
17-109 |  | 0 | 157
17-110 |  | 0 | 158
17-111 |  | 0 | 159
17-112 |  | 0 | 160
17-113 |  | 0 | 161
17-114 |  | 0 | 162
17-115 |  | 0 | 169
17-116 |  | 0 | 170
17-117 |  | 0 | 173
17-118 |  | 0 | 175
17-119 |  | 0 | 179
17-120 |  | 0 | 180
17-121 |  | 0 | 181
17-122 |  | 0 | 182
17-123 |  | 0 | 185
17-124 |  | 0 | 186
17-125 |  | 0 | 187
17-126 |  | 0 | 188
17-127 |  | 0 | 189
17-128 |  | 0 | 191
17-129 |  | 0 | 192
17-130 |  | 0 | 193
17-131 |  | 0 | 206
17-132 |  | 0 | 207
17-133 |  | 0 | 209
17-134 |  | 0 | 210
17-135 |  | 0 | 211
17-136 |  | 0 | 212
17-137 |  | 0 | 216
17-138 |  | 0 | 217
17-139 |  | 0 | 219
17-140 |  | 0 | 222
17-141 |  | 0 | 228
17-142 |  | 0 | 254
17-143 |  | 0 | 258
17-144 |  | 0 | 259
17-145 |  | 0 | 260
17-146 |  | 0 | 262
17-147 |  | 0 | 263
17-148 |  | 0 | 264
17-149 |  | 0 | 265
17-150 |  | 0 | 269
17-151 |  | 0 | 270
17-152 |  | 0 | 284
17-153 |  | 0 | 285
17-154 |  | 0 | 286
17-155 |  | 0 | 287
17-156 |  | 0 | 296
17-157 |  | 0 | 301
17-158 |  | 0 | 303
17-159 |  | 0 | 305
17-160 |  | 0 | 307
17-161 |  | 0 | 310
17-162 |  | 0 | 311
17-163 |  | 0 | 312
17-164 |  | 0 | 313
17-165 |  | 0 | 326
17-166 |  | 0 | 330
17-167 |  | 0 | 331
17-168 |  | 0 | 332
17-169 |  | 0 | 333
17-170 |  | 0 | 334
17-171 |  | 0 | 335
17-172 |  | 0 | 336
17-173 |  | 0 | 337
17-174 |  | 0 | 348
17-175 |  | 0 | 378
17-176 |  | 0 | 380
17-177 |  | 0 | 384
17-178 |  | 0 | 390
17-179 |  | 0 | 392
17-180 |  | 0 | 398
17-181 |  | 0 | 400
17-182 |  | 0 | 403
17-183 |  | 0 | 405
17-184 |  | 0 | 406
17-185 |  | 0 | 409
17-186 |  | 0 | 410
17-187 |  | 0 | 411
17-188 |  | 0 | 412
17-189 |  | 0 | 447
17-190 |  | 0 | 530
17-191 |  | 0 | 32768
17-192 |  | 0 | 32769
17-193 |  | 0 | 32770
17-194 |  | 0 | 32771
17-195 |  | 0 | 32772
17-196 |  | 0 | 32773
17-197 |  | 0 | 32774
17-198 |  | 0 | 32775
17-199 |  | 0 | 32776
17-200 |  | 0 | 32780
17-201 |  | 0 | 32781
17-202 |  | 0 | 32782
17-203 |  | 0 | 32795
17-204 |  | 0 | 32796
17-205 |  | 0 | 32798
17-206 |  | 0 | 32800
17-207 |  | 0 | 32801
17-208 |  | 0 | 32802
17-209 |  | 0 | 32803
17-210 |  | 0 | 32804
17-211 |  | 0 | 32805
17-212 |  | 0 | 32806
17-213 |  | 0 | 32807
17-214 |  | 0 | 32808
17-215 |  | 0 | 32809
17-216 |  | 0 | 32813
17-217 |  | 0 | 32821
17-218 |  | 0 | 32823
17-219 |  | 0 | 32824
17-220 |  | 0 | 32826
17-221 |  | 0 | 32827
17-222 |  | 0 | 32828
17-223 |  | 0 | 32829
17-224 |  | 0 | 32830
17-225 |  | 0 | 32831
17-226 |  | 0 | 32832
17-227 |  | 0 | 32833
17-228 |  | 0 | 32834
17-229 |  | 0 | 32835
17-230 |  | 0 | 32836
17-231 |  | 0 | 32837
17-232 |  | 0 | 32840
17-233 |  | 0 | 32841
17-234 |  | 0 | 32842
17-235 |  | 0 | 32843
17-236 |  | 0 | 32864
17-237 |  | 0 | 32865
17-238 |  | 0 | 32866
17-239 |  | 0 | 32867
17-240 |  | 0 | 32882
17-241 |  | 0 | 32891
17-242 |  | 0 | 32894
17-243 |  | 0 | 32895
17-244 |  | 0 | 32896
17-245 |  | 0 | 32901
17-246 |  | 0 | 32904
17-247 |  | 0 | 32913
17-248 |  | 0 | 32914
17-249 |  | 0 | 32915
17-250 |  | 0 | 32916
17-251 |  | 0 | 32917
17-252 |  | 0 | 32920
17-253 |  | 0 | 32922
17-254 |  | 0 | 32924
17-255 |  | 0 | 32926
17-256 |  | 0 | 32928
17-257 |  | 0 | 32929
17-258 |  | 0 | 32932
17-259 |  | 0 | 32933
17-260 |  | 0 | 32935
17-261 |  | 0 | 32936
17-262 |  | 0 | 32938
17-263 |  | 0 | 32940
17-264 |  | 0 | 32941
17-265 |  | 0 | 32942
17-266 |  | 0 | 32943
17-267 |  | 0 | 32944
17-268 |  | 0 | 32948
17-269 |  | 0 | 32952
17-270 |  | 0 | 32953
17-271 |  | 0 | 32956
17-272 |  | 0 | 32959
17-273 |  | 0 | 32960
17-274 |  | 0 | 32961
17-275 |  | 0 | 32977
17-276 |  | 0 | 32978
17-277 |  | 0 | 32979
17-278 |  | 0 | 32980
17-279 |  | 0 | 32989
17-280 |  | 0 | 32990
17-281 |  | 0 | 32991
17-282 |  | 0 | 32993
17-283 |  | 0 | 32996
17-284 |  | 0 | 32999
17-285 |  | 0 | 33076
17-286 |  | 0 | 33098
17-287 |  | 0 | 33100
17-288 |  | 0 | 33101
17-289 |  | 0 | 33102
17-290 |  | 0 | 33104
17-291 |  | 0 | 33113
17-292 |  | 0 | 33116
17-293 |  | 0 | 33117
17-294 |  | 0 | 33730
17-295 |  | 0 | 33732
17-296 |  | 0 | 34023
17-297 |  | 0 | 34025
17-298 |  | 0 | 34026
17-299 |  | 0 | 34027
17-300 |  | 0 | 34039
17-301 |  | 0 | 34040
17-302 |  | 0 | 34041
17-303 |  | 0 | 34042
17-304 |  | 0 | 34043
17-305 |  | 0 | 34044
17-306 |  | 0 | 34045
17-307 |  | 0 | 34046
17-308 |  | 0 | 34047
17-309 |  | 0 | 34048
17-310 |  | 0 | 34050
17-311 |  | 0 | 34052
17-312 |  | 0 | 34053
17-313 |  | 0 | 34055
17-314 |  | 0 | 34060
17-315 |  | 0 | 34061
17-316 |  | 0 | 34062
17-317 |  | 0 | 34063
17-318 |  | 0 | 34070
17-319 |  | 0 | 34071
17-320 |  | 0 | 34072
17-321 |  | 0 | 34073
17-322 |  | 0 | 34074
17-323 |  | 0 | 34075
17-324 |  | 0 | 34076
17-325 |  | 0 | 34077
17-326 |  | 0 | 34088
17-327 |  | 0 | 34090
17-328 |  | 0 | 34091
17-329 |  | 0 | 34094
17-330 |  | 0 | 34095
17-331 |  | 0 | 34096
17-332 |  | 0 | 34099
17-333 |  | 0 | 34100
17-334 |  | 0 | 34120
17-335 |  | 0 | 34146
17-336 |  | 0 | 34147
17-337 |  | 0 | 34148
17-338 |  | 0 | 34149
17-339 |  | 0 | 34151
17-340 |  | 0 | 34152
17-341 |  | 0 | 34153
17-342 |  | 0 | 34154
17-343 |  | 0 | 34155
17-344 |  | 0 | 34157
17-345 |  | 0 | 34160
17-346 |  | 0 | 34161
17-347 |  | 0 | 34162
17-348 |  | 0 | 34164
17-349 |  | 0 | 34165
17-350 |  | 0 | 34166
17-351 |  | 0 | 34167
17-352 |  | 0 | 34168
17-353 |  | 0 | 34171
17-354 |  | 0 | 34173
17-355 |  | 0 | 34174
17-356 |  | 0 | 34177
17-357 |  | 0 | 34178
17-358 |  | 0 | 34179
17-359 |  | 0 | 34180
17-360 |  | 0 | 34182
17-361 |  | 0 | 34183
17-362 |  | 0 | 34184
17-363 |  | 0 | 34185
17-364 |  | 0 | 34186
17-365 |  | 0 | 34187
17-366 |  | 0 | 34188
17-367 |  | 0 | 34189
17-368 |  | 0 | 34190
17-369 |  | 0 | 34191
17-370 |  | 0 | 34192
17-371 |  | 0 | 34193
17-372 |  | 0 | 34194
17-373 |  | 0 | 34195
17-374 |  | 0 | 34196
17-375 |  | 0 | 34197
17-376 |  | 0 | 34199
17-377 |  | 0 | 34202
17-378 |  | 0 | 34203
17-379 |  | 0 | 34204
17-380 |  | 0 | 34205
17-381 |  | 0 | 34206
17-382 |  | 0 | 34210
17-383 |  | 0 | 34212
17-384 |  | 0 | 34213
17-385 |  | 0 | 34215
17-386 |  | 0 | 34217
17-387 |  | 0 | 34218
17-388 |  | 0 | 34219
17-389 |  | 0 | 34220
17-390 |  | 0 | 34221
17-391 |  | 0 | 34222
17-392 |  | 0 | 34223
17-393 |  | 0 | 34224
17-394 |  | 0 | 34225
17-395 |  | 0 | 34226
17-396 |  | 0 | 34227
17-397 |  | 0 | 34228
17-398 |  | 0 | 34229
17-399 |  | 0 | 34230
17-400 |  | 0 | 34231
17-401 |  | 0 | 34232
17-402 |  | 0 | 34233
17-403 |  | 0 | 34234
17-404 |  | 0 | 34235
17-405 |  | 0 | 34238
17-406 |  | 0 | 34239
17-407 |  | 0 | 34265
17-408 |  | 0 | 34266
17-409 |  | 0 | 34273
17-410 |  | 0 | 34274
17-411 |  | 0 | 34275
17-412 |  | 0 | 34276
17-413 |  | 0 | 34277
17-414 |  | 0 | 34278
17-415 |  | 0 | 34279
17-416 |  | 0 | 34280
17-417 |  | 0 | 34281
17-418 |  | 0 | 34282
17-419 |  | 0 | 34283
17-420 |  | 0 | 34284
17-421 |  | 0 | 34285
17-422 |  | 0 | 34286
17-423 |  | 0 | 34298
17-424 |  | 0 | 34304
17-425 |  | 0 | 34816
17-426 |  | 0 | 35328
17-427 |  | 0 | 35584
17-428 |  | 0 | 34299
17-429 |  | 0 | 34300
17-430 |  | 0 | 34301
17-431 |  | 0 | 34302
17-432 |  | 0 | 33300
17-433 |  | 0 | 33301
17-434 |  | 0 | 33302
17-435 |  | 0 | 33303
17-436 |  | 0 | 33141
17-437 |  | 0 | 33142
17-438 |  | 0 | 33143
17-439 |  | 0 | 33144
17-440 |  | 0 | 33145
17-441 |  | 0 | 33146
17-442 |  | 0 | 33147
17-443 |  | 0 | 33148
17-444 |  | 0 | 33149
17-445 |  | 0 | 33150
17-446 |  | 0 | 33151
17-447 |  | 0 | 33170
17-448 |  | 0 | 33171
17-449 |  | 0 | 33172
17-450 |  | 0 | 32919
17-451 |  | 0 | 33174
17-452 |  | 0 | 33175
17-453 |  | 0 | 33176
17-454 |  | 0 | 33177
17-455 |  | 0 | 33178
17-456 |  | 0 | 33179
17-457 |  | 0 | 33180
17-458 |  | 0 | 33181
17-459 |  | 0 | 33182
17-460 |  | 0 | 33183
17-461 |  | 0 | 33184
17-462 |  | 0 | 33185
17-463 |  | 0 | 33186
17-464 |  | 0 | 33187
17-465 |  | 0 | 33188
17-466 |  | 0 | 33189
17-467 |  | 0 | 478
17-468 |  | 0 | 532
17-469 |  | 0 | 32887
17-470 |  | 0 | 32888
17-471 |  | 0 | 34069
17-472 |  | 0 | 194
17-473 |  | 0 | 32945
17-474 |  | 0 | 32946
17-475 |  | 0 | 1020
17-476 |  | 0 | 1021
17-477 |  | 0 | 1022
17-478 |  | 0 | 1019
17-479 |  | 0 | 32986
17-480 |  | 0 | 32987
17-481 |  | 0 | 359
17-482 |  | 0 | 430
17-483 |  | 0 | 437
17-484 |  | 0 | 32988
17-485 |  | 0 | 34118
17-486 |  | 0 | 34119
17-487 |  | 0 | 34243
17-488 |  | 0 | 34244
17-489 |  | 0 | 34303
17-490 |  | 0 | 34261
17-491 |  | 0 | 34246
17-492 |  | 0 | 34247
17-493 |  | 0 | 34248
17-494 |  | 0 | 34249
17-495 |  | 0 | 34262
17-496 |  | 0 | 33190
17-497 |  | 0 | 33191
17-498 |  | 0 | 33192
17-499 |  | 0 | 34117
17-500 |  | 0 | 34264
17-501 |  | 0 | 33196
17-502 |  | 0 | 33197
17-503 |  | 0 | 33198
17-504 |  | 0 | 33199
17-505 |  | 0 | 33304
17-506 |  | 0 | 33305
17-507 |  | 0 | 33306
17-508 |  | 0 | 33307
17-509 |  | 0 | 33308
17-510 |  | 0 | 33309
17-511 |  | 0 | 33310
17-512 |  | 0 | 33311
17-513 |  | 0 | 33312
17-514 |  | 0 | 33313
17-515 |  | 0 | 33314
17-516 |  | 0 | 33315
17-517 |  | 0 | 33316
17-518 |  | 0 | 33317
17-519 |  | 0 | 33318
17-520 |  | 0 | 33319
17-521 |  | 0 | 33320
17-522 |  | 0 | 33321
17-523 |  | 0 | 33322
17-524 |  | 0 | 33323
17-525 |  | 0 | 33324
17-526 |  | 0 | 33325
17-527 |  | 0 | 33326
17-528 |  | 0 | 33327
17-529 |  | 0 | 33328
17-530 |  | 0 | 33329
18 | Op.datalist com.ph.2 | 0 | 0
19 | Op.datalist com.ph.3 | 0 | 0
20 | Op.datalist com.ph.4 | 0 | 0
21 | Inval.datalist com.ph.2 | 0 | 0
22 | Inval.datalist com.ph.3 | 0 | 0
23 | Inval.datalist com.ph.4 | 0 | 0
24 | Configuration list MDT | 0 | 0
25 | All command data list | 0 | 0
26 | Conf. status bits | 0 | 0
28 | MST Error Counter | 0 | 0
29 | MDT Error Counter | 0 | 0
30 | Softwareversion | 0 | KW 211 0000 adb2080
 |  | 1 | KW 211 0000 adb2080
 |  | 2 | KW 211 0000 adb2080
 |  | 3 | KW 211 0000 adb2080
32 | Primary operat. mode | 0 | 0000H
 |  | 1 | 0000H
 |  | 2 | 0000H
 |  | 3 | 0000H
33 | Second. operat. mode1 | 0 | 0000H
 |  | 1 | 0000H
 |  | 2 | 0000H
 |  | 3 | 0000H
34 | Second. operat. mode2 | 0 | 0000H
 |  | 1 | 0000H
 |  | 2 | 0000H
 |  | 3 | 0000H
35 | Second. operat. mode3 | 0 | 0000H
 |  | 1 | 0000H
 |  | 2 | 0000H
 |  | 3 | 0000H
36 | Velocity command value | 0 | 0.0000 | 1/min
 |  | 1 | 1000.0000 | 1/min
 |  | 2 | 1000.0000 | 1/min
 |  | 3 | 1000.0000 | 1/min
37 | Velocity command value addit | 0 | 0.0000 | 1/min
 |  | 1 | 0.0000 | 1/min
 |  | 2 | 0.0000 | 1/min
 |  | 3 | 0.0000 | 1/min
38 | Pos. velocity limit | 0 | 18600.0000 | 1/min
 |  | 1 | 5000.0000 | 1/min
 |  | 2 | 5000.0000 | 1/min
 |  | 3 | 5000.0000 | 1/min
39 | Neg. velocity limit | 0 | -18600.0000 | 1/min
 |  | 1 | -5000.0000 | 1/min
 |  | 2 | -5000.0000 | 1/min
 |  | 3 | -5000.0000 | 1/min
40 | Velocity feedback value | 0 | 0.0000 | 1/min
 |  | 1 | 0.0000 | 1/min
 |  | 2 | 0.0000 | 1/min
 |  | 3 | 0.0000 | 1/min
41 | Homing velocity | 0 | 100.0000 | 1/min
 |  | 1 | 100.0000 | 1/min
 |  | 2 | 100.0000 | 1/min
 |  | 3 | 100.0000 | 1/min
42 | Homing acceleration | 0 | 100.000 | rev./ss
 |  | 1 | 100.000 | rev./ss
 |  | 2 | 100.000 | rev./ss
 |  | 3 | 100.000 | rev./ss
43 | Velocity polarity | 0 | 0000 0000 0000 0000B
 |  | 1 | 0000 0000 0000 0000B
 |  | 2 | 0000 0000 0000 0000B
 |  | 3 | 0000 0000 0000 0000B
44 | Velocity data scaling type | 0 | 0000 0000 0000 0010B
 |  | 1 | 0000 0000 0000 0010B
 |  | 2 | 0000 0000 0000 0010B
 |  | 3 | 0000 0000 0000 0010B
45 | Velocity data scaling factor | 0 | 1
 |  | 1 | 1
 |  | 2 | 1
 |  | 3 | 1
46 | Velocity data scaling expone | 0 | -4
 |  | 1 | -4
 |  | 2 | -4
 |  | 3 | -4
47 | Position command value | 0 | 0 | incr.
 |  | 1 | 0 | incr.
 |  | 2 | 0 | incr.
 |  | 3 | 0 | incr.
49 | Positive position limit | 0 | 2147483647 | incr.
 |  | 1 | 2147483647 | incr.
 |  | 2 | 2147483647 | incr.
 |  | 3 | 2147483647 | incr.
50 | Negative position limit | 0 | -2147483648 | incr.
 |  | 1 | -2147483648 | incr.
 |  | 2 | -2147483648 | incr.
 |  | 3 | -2147483648 | incr.
51 | Position feedback value | 0 | 0 | incr.
 |  | 1 | 0 | incr.
 |  | 2 | 0 | incr.
 |  | 3 | 0 | incr.
52 | Home ref. position 1 | 0 | 0 | incr.
 |  | 1 | 0 | incr.
 |  | 2 | 0 | incr.
 |  | 3 | 0 | incr.
55 | Closed loop polar. par. | 0 | 0000 0000 0000 0000B
 |  | 1 | 0000 0000 0000 0000B
 |  | 2 | 0000 0000 0000 0000B
 |  | 3 | 0000 0000 0000 0000B
57 | In position window | 0 | 1000 | incr.
 |  | 1 | 1000 | incr.
 |  | 2 | 1000 | incr.
 |  | 3 | 1000 | incr.
76 | Position data scaling type | 0 | 0000 0000 0000 0000B
 |  | 1 | 0000 0000 0000 0000B
 |  | 2 | 0000 0000 0000 0000B
 |  | 3 | 0000 0000 0000 0000B
77 | Linear position data scaling | 0 | 1
 |  | 1 | 1
 |  | 2 | 1
 |  | 3 | 1
78 | Linear position data scaling | 0 | -7
 |  | 1 | -7
 |  | 2 | -7
 |  | 3 | -7
79 | Rotational position resoluti | 0 | 3600000 | incr.
 |  | 1 | 3600000 | incr.
 |  | 2 | 3600000 | incr.
 |  | 3 | 3600000 | incr.
80 | Torque command value | 0 | 0.0 | % MN
 |  | 1 | 10.0 | % MN
 |  | 2 | 10.0 | % MN
 |  | 3 | 10.0 | % MN
81 | Torque command value additiv | 0 | 0.0 | % MN
 |  | 1 | 0.0 | % MN
 |  | 2 | 0.0 | % MN
 |  | 3 | 0.0 | % MN
82 | Positive torque limit | 0 | 200.0 | % MN
 |  | 1 | 120.0 | % MN
 |  | 2 | 120.0 | % MN
 |  | 3 | 120.0 | % MN
83 | Negative torque limit | 0 | -200.0 | % MN
 |  | 1 | -120.0 | % MN
 |  | 2 | -120.0 | % MN
 |  | 3 | -120.0 | % MN
84 | Torque feedb.val | 0 | 0.0 | % MN
 |  | 1 | 0.0 | % MN
 |  | 2 | 0.0 | % MN
 |  | 3 | 0.0 | % MN
85 | Torque polarity | 0 | 0000 0000 0000 0000B
 |  | 1 | 0000 0000 0000 0000B
 |  | 2 | 0000 0000 0000 0000B
 |  | 3 | 0000 0000 0000 0000B
86 | Torque data scaling | 0 | 0000 0000 0000 0000B
 |  | 1 | 0000 0000 0000 0000B
 |  | 2 | 0000 0000 0000 0000B
 |  | 3 | 0000 0000 0000 0000B
89 | Transmit time MDT (T2) | 0 | 1.000 | ms
91 | Bip.veloc. limit | 0 | 0.0000 | 1/min
 |  | 1 | 0.0000 | 1/min
 |  | 2 | 0.0000 | 1/min
 |  | 3 | 0.0000 | 1/min
92 | Bip.torque limit | 0 | 0.0 | % MN
 |  | 1 | 0.0 | % MN
 |  | 2 | 0.0 | % MN
 |  | 3 | 0.0 | % MN
93 | Torque scaling factor | 0 | 1
 |  | 1 | 1
 |  | 2 | 1
 |  | 3 | 1
94 | Torque scaling exponent | 0 | -2
 |  | 1 | -2
 |  | 2 | -2
 |  | 3 | -2
95 | Diagnosis | 0
96 | Slave identifier (SKLN) | 0 | 0101H
 |  | 1 | 0101H
 |  | 2 | 0101H
 |  | 3 | 0101H
97 | Diag.mask st.class 2 | 0 | 0000 0000 0000 0000B
 |  | 1 | 0000 0000 0000 0000B
 |  | 2 | 0000 0000 0000 0000B
 |  | 3 | 0000 0000 0000 0000B
98 | Diag.mask st.class 3 | 0 | 0000 0000 0000 0000B
 |  | 1 | 0000 0000 0000 0000B
 |  | 2 | 0000 0000 0000 0000B
 |  | 3 | 0000 0000 0000 0000B
99 | Diag.reset st.class 1 | 0 | 0000 0000 0000 0000B
100 | Prop.gain speed control | 0 | 40
 |  | 1 | 200
 |  | 2 | 200
 |  | 3 | 200
101 | Integr.act.time sp.ctrl | 0 | 20.0 | ms
 |  | 1 | 10.0 | ms
 |  | 2 | 10.0 | ms
 |  | 3 | 10.0 | ms
102 | Diff.time speed control | 0 | 0.0 | ms
 |  | 1 | 0.0 | ms
 |  | 2 | 0.0 | ms
 |  | 3 | 0.0 | ms
103 | Modulo value | 0 | 20000 | incr.
 |  | 1 | 20000 | incr.
 |  | 2 | 20000 | incr.
 |  | 3 | 20000 | incr.
104 | Position loop KV-factor | 0 | 20
 |  | 1 | 400
 |  | 2 | 400
 |  | 3 | 400
108 | Feedrate override | 0 | 100.00 | %
109 | Motor peak current | 0 | 105.000 | A
 |  | 1 | 5.000 | A
 |  | 2 | 5.000 | A
 |  | 3 | 5.000 | A
110 | Inverter peak current | 0 | 20.000 | A
111 | Motor nom. current | 0 | 41.000 | A
 |  | 1 | 2.500 | A
 |  | 2 | 2.500 | A
 |  | 3 | 2.500 | A
112 | Inverter nom. current | 0 | 2.500 | A
113 | Maximum speed | 0 | 18000.0000 | 1/min
 |  | 1 | 6000.0000 | 1/min
 |  | 2 | 6000.0000 | 1/min
 |  | 3 | 6000.0000 | 1/min
114 | Overload limit motor | 0 | 50.0 | %
 |  | 1 | 50.0 | %
 |  | 2 | 50.0 | %
 |  | 3 | 50.0 | %
115 | Position feedback type | 0 | 0000 0000 0000 0000B
 |  | 1 | 0000 0000 0000 0000B
 |  | 2 | 0000 0000 0000 0000B
 |  | 3 | 0000 0000 0000 0000B
116 | Resol. mot. encoder | 0 | 262144 | incr.
 |  | 1 | 20480 | incr.
 |  | 2 | 20480 | incr.
 |  | 3 | 20480 | incr.
117 | Resol. ext.pos.feedb. | 0 | 100 | incr.
 |  | 1 | 100 | incr.
 |  | 2 | 100 | incr.
 |  | 3 | 100 | incr.
121 | Load gear input rev. | 0 | 10 | rev.
 |  | 1 | 10 | rev.
 |  | 2 | 10 | rev.
 |  | 3 | 10 | rev.
122 | Load gear output rev. | 0 | 10 | rev.
 |  | 1 | 10 | rev.
 |  | 2 | 10 | rev.
 |  | 3 | 10 | rev.
123 | Feed constant | 0 | 10.0000 | mm/rev.
 |  | 1 | 10.0000 | mm/rev.
 |  | 2 | 10.0000 | mm/rev.
 |  | 3 | 10.0000 | mm/rev.
124 | Zero velocity window | 0 | 50.0000 | 1/min
 |  | 1 | 50.0000 | 1/min
 |  | 2 | 50.0000 | 1/min
 |  | 3 | 50.0000 | 1/min
125 | Velocity Threshold Nx | 0 | 1000.0000 | 1/min
 |  | 1 | 1000.0000 | 1/min
 |  | 2 | 1000.0000 | 1/min
 |  | 3 | 1000.0000 | 1/min
126 | Torque Threshold Mdx | 0 | 100.0 | % MN
 |  | 1 | 100.0 | % MN
 |  | 2 | 100.0 | % MN
 |  | 3 | 100.0 | % MN
129 | Manufact.status class 1 | 0 | 0000 0000 0000 0000B
130 | Probe1 val.p.edge | 0 | 0 | incr.
131 | Probe1 val.n.edge | 0 | 0 | incr.
132 | Probe2 val.p.edge | 0 | 0 | incr.
133 | Probe2 val.n.edge | 0 | 0 | incr.
134 | Master ctrl.word | 0 | 0000H
135 | Drive stat. word | 0 | 0000H
136 | Positive acceleration | 0 | 100.000 | rev./ss
 |  | 1 | 100.000 | rev./ss
 |  | 2 | 100.000 | rev./ss
 |  | 3 | 100.000 | rev./ss
137 | Negative acceleration | 0 | -100.000 | rev./ss
 |  | 1 | -100.000 | rev./ss
 |  | 2 | -100.000 | rev./ss
 |  | 3 | -100.000 | rev./ss
140 | Inverter type | 0
 |  | 1
 |  | 2
 |  | 3
141 | Motor type | 0 | DD5-14-10-POW
 |  | 1
 |  | 2
 |  | 3
142 | Application type | 0
 |  | 1
 |  | 2
 |  | 3
143 | SERCOS interface vers. | 0
144 | Status word | 0 | 0000H
147 | Homing par. | 0 | 1000 0000 0000 0000B
 |  | 1 | 1000 0000 0000 0000B
 |  | 2 | 1000 0000 0000 0000B
 |  | 3 | 1000 0000 0000 0000B
148 | Drive hom.cycle commd. | 0 | 0000 0000 0000 0000B
149 | Cmd. pos. stop | 0 | 0000 0000 0000 0000B
150 | Reference offset 1 | 0 | 0 | incr.
 |  | 1 | 0 | incr.
 |  | 2 | 0 | incr.
 |  | 3 | 0 | incr.
153 | Spindle angle position | 0 | 0 | incr.
 |  | 1 | 0 | incr.
 |  | 2 | 0 | incr.
 |  | 3 | 0 | incr.
154 | Spindle posit. par. | 0 | 1000 0000 0000 0000B
 |  | 1 | 1000 0000 0000 0000B
 |  | 2 | 1000 0000 0000 0000B
 |  | 3 | 1000 0000 0000 0000B
157 | Velocity window | 0 | 100.0000 | 1/min
 |  | 1 | 100.0000 | 1/min
 |  | 2 | 100.0000 | 1/min
 |  | 3 | 100.0000 | 1/min
158 | Power threshold Px | 0 | 100 | W
 |  | 1 | 100 | W
 |  | 2 | 100 | W
 |  | 3 | 100 | W
159 | Excess Error | 0 | 1000000 | incr.
 |  | 1 | 1000000 | incr.
 |  | 2 | 1000000 | incr.
 |  | 3 | 1000000 | incr.
160 | Acceleration data scaling ty | 0 | 0000 0000 0000 0010B
 |  | 1 | 0000 0000 0000 0010B
 |  | 2 | 0000 0000 0000 0010B
 |  | 3 | 0000 0000 0000 0010B
161 | Acceleration data scaling fa | 0 | 1
 |  | 1 | 1
 |  | 2 | 1
 |  | 3 | 1
162 | Acceleration data scaling ex | 0 | -3
 |  | 1 | -3
 |  | 2 | -3
 |  | 3 | -3
169 | Probe ctrl. par. | 0 | 0000 0000 0000 0000B
 |  | 1 | 0000 0000 0000 0000B
 |  | 2 | 0000 0000 0000 0000B
 |  | 3 | 0000 0000 0000 0000B
170 | Cmd. Probe.cycle | 0 | 0000 0000 0000 0000B
173 | Marker posit. A | 0 | 0 | incr.
175 | Displacement Parameter 1 | 0 | 0 | incr.
 |  | 1 | 0 | incr.
 |  | 2 | 0 | incr.
 |  | 3 | 0 | incr.
179 | Probe status | 0 | 0000 0000 0000 0000B
180 | Spindle rel. offset | 0 | 10000 | incr.
 |  | 1 | 10000 | incr.
 |  | 2 | 10000 | incr.
 |  | 3 | 10000 | incr.
181 | Diag. manufact. class 2 | 0 | 0000 0000 0000 0000B
182 | Diag. manufact. Status | 0 | 0000 0000 0000 0000B
185 | Length data AT | 0 | 32 | byte
186 | Length data MDT | 0 | 32 | byte
187 | List of data AT | 0 | 0
188 | List of data MDT | 0 | 0
189 | Following dist. | 0 | 0 | incr.
 |  | 1 | 0 | incr.
 |  | 2 | 0 | incr.
 |  | 3 | 0 | incr.
191 | Cmd. cancel ref. point | 0 | 0000 0000 0000 0000B
192 | List backup data | 0 | 0
193 | Positioning jerk | 0 | 0.000 | rev./sss
194 | Acceleration setpoint | 0 | 0.000 | rev./ss
 |  | 1 | 0.000 | rev./ss
 |  | 2 | 0.000 | rev./ss
 |  | 3 | 0.000 | rev./ss
206 | Drive on delay time | 0 | 0.0 | ms
 |  | 1 | 0.0 | ms
 |  | 2 | 0.0 | ms
 |  | 3 | 0.0 | ms
207 | Drive off delay time | 0 | 0.0 | ms
 |  | 1 | 0.0 | ms
 |  | 2 | 0.0 | ms
 |  | 3 | 0.0 | ms
209 | Lower adaption limit | 0 | 0.0000 | 1/min
 |  | 1 | 0.0000 | 1/min
 |  | 2 | 0.0000 | 1/min
 |  | 3 | 0.0000 | 1/min
210 | Upper adaption limit | 0 | 0.0000 | 1/min
 |  | 1 | 0.0000 | 1/min
 |  | 2 | 0.0000 | 1/min
 |  | 3 | 0.0000 | 1/min
211 | Prop. gain adaptation | 0 | 100.0 | %
 |  | 1 | 100.0 | %
 |  | 2 | 100.0 | %
 |  | 3 | 100.0 | %
212 | Integ.action time adap. | 0 | 100.0 | %
 |  | 1 | 100.0 | %
 |  | 2 | 100.0 | %
 |  | 3 | 100.0 | %
216 | Switch par. set comm. | 0 | 0000 0000 0000 0000B
217 | Preselect parameter set | 0 | 0000 0000 0000 0000B
219 | List parameter set | 0 | 0
222 | Spindle pos. speed | 0 | 300.0000 | 1/min
 |  | 1 | 300.0000 | 1/min
 |  | 2 | 300.0000 | 1/min
 |  | 3 | 300.0000 | 1/min
228 | Synchr. pos. window | 0 | 1000 | incr.
 |  | 1 | 1000 | incr.
 |  | 2 | 1000 | incr.
 |  | 3 | 1000 | incr.
254 | Act. Par. set | 0 | 0000 0000 0000 0000B
258 | Target position | 0 | 0 | incr.
259 | Positioning velocity | 0 | 0.0000 | 1/min
260 | Positioning acceleration | 0 | 0.000 | rev./ss
262 | Init.prog.load.comm. | 0 | 0000 0000 0000 0000B
263 | Cmd. load data | 0 | 0000 0000 0000 0000B
264 | Cmd. save data | 0 | 0000 0000 0000 0000B
265 | Language | 0 | 0001H
269 | ID memory mode | 0 | 0000 0000 0000 0000B
270 | Temp. par. list | 0 | 92
270-2 |  | 0 | 36
270-3 |  | 0 | 38
270-4 |  | 0 | 39
270-5 |  | 0 | 41
270-6 |  | 0 | 42
270-7 |  | 0 | 49
270-8 |  | 0 | 50
270-9 |  | 0 | 52
270-10 |  | 0 | 80
270-11 |  | 0 | 82
270-12 |  | 0 | 83
270-13 |  | 0 | 91
270-14 |  | 0 | 92
270-15 |  | 0 | 100
270-16 |  | 0 | 101
270-17 |  | 0 | 102
270-18 |  | 0 | 104
270-19 |  | 0 | 124
270-20 |  | 0 | 125
270-21 |  | 0 | 126
270-22 |  | 0 | 136
270-23 |  | 0 | 137
270-24 |  | 0 | 147
270-25 |  | 0 | 150
270-26 |  | 0 | 153
270-27 |  | 0 | 154
270-28 |  | 0 | 157
270-29 |  | 0 | 158
270-30 |  | 0 | 159
270-31 |  | 0 | 169
270-32 |  | 0 | 180
270-33 |  | 0 | 222
270-34 |  | 0 | 228
270-35 |  | 0 | 265
270-36 |  | 0 | 296
270-37 |  | 0 | 301
270-38 |  | 0 | 303
270-39 |  | 0 | 305
270-40 |  | 0 | 307
270-41 |  | 0 | 348
270-42 |  | 0 | 392
270-43 |  | 0 | 530
270-44 |  | 0 | 32780
270-45 |  | 0 | 32781
270-46 |  | 0 | 32894
270-47 |  | 0 | 32895
270-48 |  | 0 | 32916
270-49 |  | 0 | 32917
270-50 |  | 0 | 32926
270-51 |  | 0 | 32928
270-52 |  | 0 | 32929
270-53 |  | 0 | 32935
270-54 |  | 0 | 34050
270-55 |  | 0 | 34052
270-56 |  | 0 | 34148
270-57 |  | 0 | 34149
270-58 |  | 0 | 34151
270-59 |  | 0 | 34152
270-60 |  | 0 | 34154
270-61 |  | 0 | 34155
270-62 |  | 0 | 34177
270-63 |  | 0 | 34178
270-64 |  | 0 | 34179
270-65 |  | 0 | 34180
270-66 |  | 0 | 34182
270-67 |  | 0 | 34189
270-68 |  | 0 | 34190
270-69 |  | 0 | 34221
270-70 |  | 0 | 34222
270-71 |  | 0 | 34223
270-72 |  | 0 | 34224
270-73 |  | 0 | 34227
270-74 |  | 0 | 34285
270-75 |  | 0 | 33300
270-76 |  | 0 | 33301
270-77 |  | 0 | 33302
270-78 |  | 0 | 33303
270-79 |  | 0 | 33141
270-80 |  | 0 | 33144
270-81 |  | 0 | 33174
270-82 |  | 0 | 33175
270-83 |  | 0 | 34246
270-84 |  | 0 | 34247
270-85 |  | 0 | 34248
270-86 |  | 0 | 34249
270-87 |  | 0 | 33190
270-88 |  | 0 | 33191
270-89 |  | 0 | 33192
270-90 |  | 0 | 34264
270-91 |  | 0 | 33305
270-92 |  | 0 | 33306
270-93 |  | 0 | 33307
284 | Operation mode 4 | 0 | 0000H
 |  | 1 | 0000H
 |  | 2 | 0000H
 |  | 3 | 0000H
285 | Operation mode 5 | 0 | 0000H
 |  | 1 | 0000H
 |  | 2 | 0000H
 |  | 3 | 0000H
286 | Operation mode 6 | 0 | 0000H
 |  | 1 | 0000H
 |  | 2 | 0000H
 |  | 3 | 0000H
287 | Operation mode 7 | 0 | 0000H
 |  | 1 | 0000H
 |  | 2 | 0000H
 |  | 3 | 0000H
296 | Velocity feed forward gain | 0 | 100 | %
 |  | 1 | 100 | %
 |  | 2 | 100 | %
 |  | 3 | 100 | %
301 | Alloc. control bit 1 | 0 | 0
 |  | 1 | 0
 |  | 2 | 0
 |  | 3 | 0
303 | Alloc. control bit 2 | 0 | 0
 |  | 1 | 0
 |  | 2 | 0
 |  | 3 | 0
305 | Alloc. status bit 1 | 0 | 0
 |  | 1 | 0
 |  | 2 | 0
 |  | 3 | 0
307 | Alloc. status bit 2 | 0 | 0
 |  | 1 | 0
 |  | 2 | 0
 |  | 3 | 0
310 | Overload motor | 0 | 0000 0000 0000 0000B
311 | Warn. overtemp. inv. | 0 | 0000 0000 0000 0000B
312 | Warn. overtemp. mot. | 0 | 0000 0000 0000 0000B
313 | Warning cooler | 0 | 0000 0000 0000 0000B
326 | Par. checksum | 0 | 0
330 | Message Nact = Nset | 0 | 0000 0000 0000 0000B
331 | Message Nact < Nmin | 0 | 0000 0000 0000 0000B
332 | Message Nact < Nx | 0 | 0000 0000 0000 0000B
333 | Message Md >= Mdx | 0 | 0000 0000 0000 0000B
334 | Message Md >= Mdlimit | 0 | 0000 0000 0000 0000B
335 | Message Ncomm > Nlimit | 0 | 0000 0000 0000 0000B
336 | Message In Position | 0 | 0000 0000 0000 0000B
337 | Message P >= Px | 0 | 0000 0000 0000 0000B
348 | Acc. feed forward gain | 0 | 0 | %
 |  | 1 | 0 | %
 |  | 2 | 0 | %
 |  | 3 | 0 | %
359 | Positioning deceleration | 0 | 0.000 | rev./ss
378 | Abs. encoder range 1 | 0 | 0 | incr.
 |  | 1 | 0 | incr.
 |  | 2 | 0 | incr.
 |  | 3 | 0 | incr.
380 | DC-bus voltage | 0 | 0 | V
384 | Temperature internal | 0 | 0.0 | grd C
390 | Diagnostic number | 0 | 0
392 | Velocity feedback filter | 0 | 1000 | us
 |  | 1 | 1000 | us
 |  | 2 | 1000 | us
 |  | 3 | 1000 | us
398 | List status bits | 0 | 0
400 | Home switch | 0 | 0000 0000 0000 0000B
403 | Status act. pos. value | 0 | 0000 0000 0000 0000B
405 | Probe 1 enable | 0 | 0000 0000 0000 0000B
406 | Probe 2 enable | 0 | 0000 0000 0000 0000B
409 | Probe1 pos.latch | 0 | 0000 0000 0000 0000B
410 | Probe1 neg.latch | 0 | 0000 0000 0000 0000B
411 | Probe2 pos.latch | 0 | 0000 0000 0000 0000B
412 | Probe2 neg.latch | 0 | 0000 0000 0000 0000B
430 | Active target position | 0 | 0 | incr.
437 | Positioning status | 0 | 0000 0000 0000 0000B
447 | Cmd. set abs. position | 0 | 0000 0000 0000 0000B
478 | Limit switch status | 0 | 0000 0000 0000 0000B
530 | Clamping torque | 0 | 100.0 | % MN
 |  | 1 | 100.0 | % MN
 |  | 2 | 100.0 | % MN
 |  | 3 | 100.0 | % MN
532 | Limit switch control | 0 | 0000 0000 0000 0000B
1019 | MAC address | 0 | 0
1020 | IP address | 0 | 0
1021 | Subnet mask | 0 | 0
1022 | Gateway address | 0 | 0
32768 | Nom. motor voltage | 0 | 350.0 | V
 |  | 1 | 350.0 | V
 |  | 2 | 350.0 | V
 |  | 3 | 350.0 | V
32769 | Magnet. current IM | 0 | 35.000 | A
 |  | 1 | 1.500 | A
 |  | 2 | 1.500 | A
 |  | 3 | 1.500 | A
32770 | Magnet. current IM1 | 0 | 0.000 | A
 |  | 1 | 1.000 | A
 |  | 2 | 1.000 | A
 |  | 3 | 1.000 | A
32771 | Nom. torque | 0 | 9.8 | Nm
 |  | 1 | 2.0 | Nm
 |  | 2 | 2.0 | Nm
 |  | 3 | 2.0 | Nm
32772 | Nom. velocity | 0 | 12000.0000 | 1/min
 |  | 1 | 3000.0000 | 1/min
 |  | 2 | 3000.0000 | 1/min
 |  | 3 | 3000.0000 | 1/min
32773 | Service bits | 0 | 0000 0000 0000 0000 0101 0000 0000 0001B
 |  | 1 | 0000 0000 0000 0000 0001 0000 0000 0101B
 |  | 2 | 0000 0000 0000 0000 0001 0000 0000 0101B
 |  | 3 | 0000 0000 0000 0000 0001 0000 0000 0101B
32774 | Rotor time constant | 0 | 0.0100 | s
 |  | 1 | 0.0360 | s
 |  | 2 | 0.0360 | s
 |  | 3 | 0.0360 | s
32775 | Pole number motor | 0 | 10
 |  | 1 | 4
 |  | 2 | 4
 |  | 3 | 4
32776 | Sinus encoder period | 0 | 16384
 |  | 1 | 1024
 |  | 2 | 1024
 |  | 3 | 1024
32780 | Accel. ramp | 0 | 100.0 | ms
 |  | 1 | 100.0 | ms
 |  | 2 | 100.0 | ms
 |  | 3 | 100.0 | ms
32781 | Decel. ramp | 0 | 100.0 | ms
 |  | 1 | 100.0 | ms
 |  | 2 | 100.0 | ms
 |  | 3 | 100.0 | ms
32782 | Decel.ramp RF inactive | 0 | 100.0 | ms
 |  | 1 | 100.0 | ms
 |  | 2 | 100.0 | ms
 |  | 3 | 100.0 | ms
32795 | Source UE | 0 | 0
32796 | Source RF | 0 | 5
32798 | User list 1 | 0 | 11
32798-2 |  | 0 | 0001H
32798-3 |  | 0 | 01F4H
32798-4 |  | 0 | 0032H
32798-5 |  | 0 | 01F4H
32798-6 |  | 0 | 0258H
32798-7 |  | 0 | 01C2H
32798-8 |  | 0 | 047EH
32798-9 |  | 0 | 04E2H
32798-10 |  | 0 | 00FAH
32798-11 |  | 0 | 04E2H
32798-12 |  | 0 | 0578H
32800 | AMK main op. mode | 0 | 00480002H
 |  | 1 | 00430043H
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

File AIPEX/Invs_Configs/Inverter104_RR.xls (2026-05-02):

Id | Name | P-Set | Value | Unit | Remark
1 | NC cycle time | 0 | 1.000 | ms
2 | SERCOS cycle time | 0 | 1.000 | ms
6 | Drive telegr.start.time | 0 | 0.200 | ms
7 | Feedb.acquis.start.time | 0 | 0.000 | ms
8 | Command valid time (T3) | 0 | 0.000 | ms
11 | Status class 1-errors | 0 | 1000 0000 0000 0000B
12 | Status class 2-warnings | 0 | 0000 0000 0000 0000B
13 | Status class 3-messages | 0 | 0000 0000 0000 0110B
15 | Telegr. type par. | 0 | 6
16 | Configuration list AT | 0 | 0
17 | ID-No.list all op.data | 0 | 497
17-2 |  | 0 | 1
17-3 |  | 0 | 2
17-4 |  | 0 | 6
17-5 |  | 0 | 7
17-6 |  | 0 | 8
17-7 |  | 0 | 11
17-8 |  | 0 | 12
17-9 |  | 0 | 13
17-10 |  | 0 | 15
17-11 |  | 0 | 16
17-12 |  | 0 | 17
17-13 |  | 0 | 18
17-14 |  | 0 | 19
17-15 |  | 0 | 20
17-16 |  | 0 | 21
17-17 |  | 0 | 22
17-18 |  | 0 | 23
17-19 |  | 0 | 24
17-20 |  | 0 | 25
17-21 |  | 0 | 26
17-22 |  | 0 | 28
17-23 |  | 0 | 29
17-24 |  | 0 | 30
17-25 |  | 0 | 32
17-26 |  | 0 | 33
17-27 |  | 0 | 34
17-28 |  | 0 | 35
17-29 |  | 0 | 36
17-30 |  | 0 | 37
17-31 |  | 0 | 38
17-32 |  | 0 | 39
17-33 |  | 0 | 40
17-34 |  | 0 | 41
17-35 |  | 0 | 42
17-36 |  | 0 | 43
17-37 |  | 0 | 44
17-38 |  | 0 | 45
17-39 |  | 0 | 46
17-40 |  | 0 | 47
17-41 |  | 0 | 49
17-42 |  | 0 | 50
17-43 |  | 0 | 51
17-44 |  | 0 | 52
17-45 |  | 0 | 55
17-46 |  | 0 | 57
17-47 |  | 0 | 76
17-48 |  | 0 | 77
17-49 |  | 0 | 78
17-50 |  | 0 | 79
17-51 |  | 0 | 80
17-52 |  | 0 | 81
17-53 |  | 0 | 82
17-54 |  | 0 | 83
17-55 |  | 0 | 84
17-56 |  | 0 | 85
17-57 |  | 0 | 86
17-58 |  | 0 | 89
17-59 |  | 0 | 91
17-60 |  | 0 | 92
17-61 |  | 0 | 93
17-62 |  | 0 | 94
17-63 |  | 0 | 95
17-64 |  | 0 | 96
17-65 |  | 0 | 97
17-66 |  | 0 | 98
17-67 |  | 0 | 99
17-68 |  | 0 | 100
17-69 |  | 0 | 101
17-70 |  | 0 | 102
17-71 |  | 0 | 103
17-72 |  | 0 | 104
17-73 |  | 0 | 108
17-74 |  | 0 | 109
17-75 |  | 0 | 110
17-76 |  | 0 | 111
17-77 |  | 0 | 112
17-78 |  | 0 | 113
17-79 |  | 0 | 114
17-80 |  | 0 | 115
17-81 |  | 0 | 116
17-82 |  | 0 | 117
17-83 |  | 0 | 121
17-84 |  | 0 | 122
17-85 |  | 0 | 123
17-86 |  | 0 | 124
17-87 |  | 0 | 125
17-88 |  | 0 | 126
17-89 |  | 0 | 129
17-90 |  | 0 | 130
17-91 |  | 0 | 131
17-92 |  | 0 | 132
17-93 |  | 0 | 133
17-94 |  | 0 | 134
17-95 |  | 0 | 135
17-96 |  | 0 | 136
17-97 |  | 0 | 137
17-98 |  | 0 | 140
17-99 |  | 0 | 141
17-100 |  | 0 | 142
17-101 |  | 0 | 143
17-102 |  | 0 | 144
17-103 |  | 0 | 147
17-104 |  | 0 | 148
17-105 |  | 0 | 149
17-106 |  | 0 | 150
17-107 |  | 0 | 153
17-108 |  | 0 | 154
17-109 |  | 0 | 157
17-110 |  | 0 | 158
17-111 |  | 0 | 159
17-112 |  | 0 | 160
17-113 |  | 0 | 161
17-114 |  | 0 | 162
17-115 |  | 0 | 169
17-116 |  | 0 | 170
17-117 |  | 0 | 173
17-118 |  | 0 | 175
17-119 |  | 0 | 179
17-120 |  | 0 | 180
17-121 |  | 0 | 181
17-122 |  | 0 | 182
17-123 |  | 0 | 185
17-124 |  | 0 | 186
17-125 |  | 0 | 187
17-126 |  | 0 | 188
17-127 |  | 0 | 189
17-128 |  | 0 | 191
17-129 |  | 0 | 192
17-130 |  | 0 | 193
17-131 |  | 0 | 194
17-132 |  | 0 | 206
17-133 |  | 0 | 207
17-134 |  | 0 | 209
17-135 |  | 0 | 210
17-136 |  | 0 | 211
17-137 |  | 0 | 212
17-138 |  | 0 | 216
17-139 |  | 0 | 217
17-140 |  | 0 | 219
17-141 |  | 0 | 222
17-142 |  | 0 | 228
17-143 |  | 0 | 254
17-144 |  | 0 | 258
17-145 |  | 0 | 259
17-146 |  | 0 | 260
17-147 |  | 0 | 262
17-148 |  | 0 | 263
17-149 |  | 0 | 264
17-150 |  | 0 | 265
17-151 |  | 0 | 269
17-152 |  | 0 | 270
17-153 |  | 0 | 284
17-154 |  | 0 | 285
17-155 |  | 0 | 286
17-156 |  | 0 | 287
17-157 |  | 0 | 296
17-158 |  | 0 | 301
17-159 |  | 0 | 303
17-160 |  | 0 | 305
17-161 |  | 0 | 307
17-162 |  | 0 | 310
17-163 |  | 0 | 311
17-164 |  | 0 | 312
17-165 |  | 0 | 313
17-166 |  | 0 | 326
17-167 |  | 0 | 330
17-168 |  | 0 | 331
17-169 |  | 0 | 332
17-170 |  | 0 | 333
17-171 |  | 0 | 334
17-172 |  | 0 | 335
17-173 |  | 0 | 336
17-174 |  | 0 | 337
17-175 |  | 0 | 348
17-176 |  | 0 | 359
17-177 |  | 0 | 378
17-178 |  | 0 | 380
17-179 |  | 0 | 384
17-180 |  | 0 | 390
17-181 |  | 0 | 392
17-182 |  | 0 | 398
17-183 |  | 0 | 400
17-184 |  | 0 | 403
17-185 |  | 0 | 405
17-186 |  | 0 | 406
17-187 |  | 0 | 409
17-188 |  | 0 | 410
17-189 |  | 0 | 411
17-190 |  | 0 | 412
17-191 |  | 0 | 430
17-192 |  | 0 | 437
17-193 |  | 0 | 447
17-194 |  | 0 | 478
17-195 |  | 0 | 530
17-196 |  | 0 | 532
17-197 |  | 0 | 1019
17-198 |  | 0 | 1020
17-199 |  | 0 | 1021
17-200 |  | 0 | 1022
17-201 |  | 0 | 32768
17-202 |  | 0 | 32769
17-203 |  | 0 | 32770
17-204 |  | 0 | 32771
17-205 |  | 0 | 32772
17-206 |  | 0 | 32773
17-207 |  | 0 | 32774
17-208 |  | 0 | 32775
17-209 |  | 0 | 32776
17-210 |  | 0 | 32780
17-211 |  | 0 | 32781
17-212 |  | 0 | 32782
17-213 |  | 0 | 32795
17-214 |  | 0 | 32796
17-215 |  | 0 | 32798
17-216 |  | 0 | 32800
17-217 |  | 0 | 32801
17-218 |  | 0 | 32802
17-219 |  | 0 | 32803
17-220 |  | 0 | 32804
17-221 |  | 0 | 32805
17-222 |  | 0 | 32806
17-223 |  | 0 | 32807
17-224 |  | 0 | 32808
17-225 |  | 0 | 32809
17-226 |  | 0 | 32813
17-227 |  | 0 | 32821
17-228 |  | 0 | 32823
17-229 |  | 0 | 32824
17-230 |  | 0 | 32826
17-231 |  | 0 | 32827
17-232 |  | 0 | 32828
17-233 |  | 0 | 32829
17-234 |  | 0 | 32830
17-235 |  | 0 | 32831
17-236 |  | 0 | 32832
17-237 |  | 0 | 32833
17-238 |  | 0 | 32834
17-239 |  | 0 | 32835
17-240 |  | 0 | 32836
17-241 |  | 0 | 32837
17-242 |  | 0 | 32840
17-243 |  | 0 | 32841
17-244 |  | 0 | 32842
17-245 |  | 0 | 32843
17-246 |  | 0 | 32864
17-247 |  | 0 | 32865
17-248 |  | 0 | 32866
17-249 |  | 0 | 32867
17-250 |  | 0 | 32882
17-251 |  | 0 | 32887
17-252 |  | 0 | 32888
17-253 |  | 0 | 32891
17-254 |  | 0 | 32894
17-255 |  | 0 | 32895
17-256 |  | 0 | 32896
17-257 |  | 0 | 32901
17-258 |  | 0 | 32904
17-259 |  | 0 | 32913
17-260 |  | 0 | 32914
17-261 |  | 0 | 32915
17-262 |  | 0 | 32916
17-263 |  | 0 | 32919
17-264 |  | 0 | 32920
17-265 |  | 0 | 32922
17-266 |  | 0 | 32924
17-267 |  | 0 | 32926
17-268 |  | 0 | 32928
17-269 |  | 0 | 32929
17-270 |  | 0 | 32932
17-271 |  | 0 | 32933
17-272 |  | 0 | 32935
17-273 |  | 0 | 32936
17-274 |  | 0 | 32938
17-275 |  | 0 | 32940
17-276 |  | 0 | 32941
17-277 |  | 0 | 32942
17-278 |  | 0 | 32943
17-279 |  | 0 | 32944
17-280 |  | 0 | 32945
17-281 |  | 0 | 32946
17-282 |  | 0 | 32948
17-283 |  | 0 | 32952
17-284 |  | 0 | 32953
17-285 |  | 0 | 32956
17-286 |  | 0 | 32959
17-287 |  | 0 | 32960
17-288 |  | 0 | 32961
17-289 |  | 0 | 32977
17-290 |  | 0 | 32978
17-291 |  | 0 | 32979
17-292 |  | 0 | 32980
17-293 |  | 0 | 32986
17-294 |  | 0 | 32987
17-295 |  | 0 | 32988
17-296 |  | 0 | 32989
17-297 |  | 0 | 32990
17-298 |  | 0 | 32991
17-299 |  | 0 | 32993
17-300 |  | 0 | 32996
17-301 |  | 0 | 32999
17-302 |  | 0 | 33076
17-303 |  | 0 | 33098
17-304 |  | 0 | 33100
17-305 |  | 0 | 33101
17-306 |  | 0 | 33102
17-307 |  | 0 | 33104
17-308 |  | 0 | 33113
17-309 |  | 0 | 33116
17-310 |  | 0 | 33117
17-311 |  | 0 | 33141
17-312 |  | 0 | 33142
17-313 |  | 0 | 33143
17-314 |  | 0 | 33144
17-315 |  | 0 | 33145
17-316 |  | 0 | 33146
17-317 |  | 0 | 33147
17-318 |  | 0 | 33148
17-319 |  | 0 | 33149
17-320 |  | 0 | 33150
17-321 |  | 0 | 33151
17-322 |  | 0 | 33170
17-323 |  | 0 | 33171
17-324 |  | 0 | 33172
17-325 |  | 0 | 33174
17-326 |  | 0 | 33175
17-327 |  | 0 | 33176
17-328 |  | 0 | 33177
17-329 |  | 0 | 33178
17-330 |  | 0 | 33179
17-331 |  | 0 | 33180
17-332 |  | 0 | 33181
17-333 |  | 0 | 33182
17-334 |  | 0 | 33183
17-335 |  | 0 | 33184
17-336 |  | 0 | 33185
17-337 |  | 0 | 33186
17-338 |  | 0 | 33187
17-339 |  | 0 | 33188
17-340 |  | 0 | 33189
17-341 |  | 0 | 33190
17-342 |  | 0 | 33191
17-343 |  | 0 | 33192
17-344 |  | 0 | 33300
17-345 |  | 0 | 33301
17-346 |  | 0 | 33302
17-347 |  | 0 | 33303
17-348 |  | 0 | 33730
17-349 |  | 0 | 33732
17-350 |  | 0 | 34023
17-351 |  | 0 | 34025
17-352 |  | 0 | 34026
17-353 |  | 0 | 34027
17-354 |  | 0 | 34039
17-355 |  | 0 | 34040
17-356 |  | 0 | 34041
17-357 |  | 0 | 34042
17-358 |  | 0 | 34043
17-359 |  | 0 | 34044
17-360 |  | 0 | 34045
17-361 |  | 0 | 34046
17-362 |  | 0 | 34047
17-363 |  | 0 | 34048
17-364 |  | 0 | 34050
17-365 |  | 0 | 34052
17-366 |  | 0 | 34053
17-367 |  | 0 | 34055
17-368 |  | 0 | 34060
17-369 |  | 0 | 34061
17-370 |  | 0 | 34062
17-371 |  | 0 | 34063
17-372 |  | 0 | 34069
17-373 |  | 0 | 34070
17-374 |  | 0 | 34071
17-375 |  | 0 | 34072
17-376 |  | 0 | 34073
17-377 |  | 0 | 34074
17-378 |  | 0 | 34075
17-379 |  | 0 | 34076
17-380 |  | 0 | 34077
17-381 |  | 0 | 34088
17-382 |  | 0 | 34090
17-383 |  | 0 | 34091
17-384 |  | 0 | 34094
17-385 |  | 0 | 34095
17-386 |  | 0 | 34096
17-387 |  | 0 | 34099
17-388 |  | 0 | 34100
17-389 |  | 0 | 34117
17-390 |  | 0 | 34118
17-391 |  | 0 | 34119
17-392 |  | 0 | 34120
17-393 |  | 0 | 34146
17-394 |  | 0 | 34147
17-395 |  | 0 | 34148
17-396 |  | 0 | 34149
17-397 |  | 0 | 34151
17-398 |  | 0 | 34152
17-399 |  | 0 | 34153
17-400 |  | 0 | 34154
17-401 |  | 0 | 34155
17-402 |  | 0 | 34157
17-403 |  | 0 | 34160
17-404 |  | 0 | 34161
17-405 |  | 0 | 34162
17-406 |  | 0 | 34164
17-407 |  | 0 | 34165
17-408 |  | 0 | 34166
17-409 |  | 0 | 34167
17-410 |  | 0 | 34168
17-411 |  | 0 | 34171
17-412 |  | 0 | 34174
17-413 |  | 0 | 34177
17-414 |  | 0 | 34178
17-415 |  | 0 | 34179
17-416 |  | 0 | 34180
17-417 |  | 0 | 34182
17-418 |  | 0 | 34183
17-419 |  | 0 | 34184
17-420 |  | 0 | 34185
17-421 |  | 0 | 34186
17-422 |  | 0 | 34187
17-423 |  | 0 | 34188
17-424 |  | 0 | 34189
17-425 |  | 0 | 34190
17-426 |  | 0 | 34191
17-427 |  | 0 | 34192
17-428 |  | 0 | 34193
17-429 |  | 0 | 34194
17-430 |  | 0 | 34195
17-431 |  | 0 | 34196
17-432 |  | 0 | 34197
17-433 |  | 0 | 34199
17-434 |  | 0 | 34202
17-435 |  | 0 | 34203
17-436 |  | 0 | 34204
17-437 |  | 0 | 34205
17-438 |  | 0 | 34206
17-439 |  | 0 | 34210
17-440 |  | 0 | 34212
17-441 |  | 0 | 34213
17-442 |  | 0 | 34215
17-443 |  | 0 | 34217
17-444 |  | 0 | 34218
17-445 |  | 0 | 34219
17-446 |  | 0 | 34220
17-447 |  | 0 | 34221
17-448 |  | 0 | 34222
17-449 |  | 0 | 34223
17-450 |  | 0 | 34224
17-451 |  | 0 | 34225
17-452 |  | 0 | 34226
17-453 |  | 0 | 34227
17-454 |  | 0 | 34228
17-455 |  | 0 | 34229
17-456 |  | 0 | 34230
17-457 |  | 0 | 34231
17-458 |  | 0 | 34232
17-459 |  | 0 | 34233
17-460 |  | 0 | 34234
17-461 |  | 0 | 34235
17-462 |  | 0 | 34238
17-463 |  | 0 | 34239
17-464 |  | 0 | 34243
17-465 |  | 0 | 34244
17-466 |  | 0 | 34246
17-467 |  | 0 | 34247
17-468 |  | 0 | 34248
17-469 |  | 0 | 34249
17-470 |  | 0 | 34261
17-471 |  | 0 | 34262
17-472 |  | 0 | 34264
17-473 |  | 0 | 34265
17-474 |  | 0 | 34266
17-475 |  | 0 | 34273
17-476 |  | 0 | 34274
17-477 |  | 0 | 34275
17-478 |  | 0 | 34276
17-479 |  | 0 | 34277
17-480 |  | 0 | 34278
17-481 |  | 0 | 34279
17-482 |  | 0 | 34280
17-483 |  | 0 | 34281
17-484 |  | 0 | 34282
17-485 |  | 0 | 34283
17-486 |  | 0 | 34284
17-487 |  | 0 | 34285
17-488 |  | 0 | 34286
17-489 |  | 0 | 34298
17-490 |  | 0 | 34299
17-491 |  | 0 | 34300
17-492 |  | 0 | 34301
17-493 |  | 0 | 34302
17-494 |  | 0 | 34303
17-495 |  | 0 | 34304
17-496 |  | 0 | 34816
17-497 |  | 0 | 35328
17-498 |  | 0 | 35584
18 | Op.datalist com.ph.2 | 0 | 4
18-2 |  | 0 | 2
18-3 |  | 0 | 6
18-4 |  | 0 | 15
18-5 |  | 0 | 89
19 | Op.datalist com.ph.3 | 0 | 0
20 | Op.datalist com.ph.4 | 0 | 0
21 | Inval.datalist com.ph.2 | 0 | 0
22 | Inval.datalist com.ph.3 | 0 | 0
23 | Inval.datalist com.ph.4 | 0 | 0
24 | Configuration list MDT | 0 | 0
25 | All command data list | 0 | 4
25-2 |  | 0 | 99
25-3 |  | 0 | 148
25-4 |  | 0 | 170
25-5 |  | 0 | 216
26 | Conf. status bits | 0 | 0
28 | MST Error Counter | 0 | 0
29 | MDT Error Counter | 0 | 0
30 | Softwareversion | 0 | KW 211 1951 207666
 |  | 1
 |  | 2 | MON 308
 |  | 3 | FPG 1 0 P2 0 975
32 | Primary operat. mode | 0 | 0001H
 |  | 1 | 0001H
 |  | 2 | 0001H
 |  | 3 | 0001H
33 | Second. operat. mode1 | 0 | 0002H
 |  | 1 | 0002H
 |  | 2 | 0002H
 |  | 3 | 0002H
34 | Second. operat. mode2 | 0 | 0002H
 |  | 1 | 0002H
 |  | 2 | 0002H
 |  | 3 | 0002H
35 | Second. operat. mode3 | 0 | 0002H
 |  | 1 | 0002H
 |  | 2 | 0002H
 |  | 3 | 0002H
36 | Velocity command value | 0 | 0.0000 | 1/min
 |  | 1 | 1000.0000 | 1/min
 |  | 2 | 1000.0000 | 1/min
 |  | 3 | 1000.0000 | 1/min
37 | Velocity command value addit | 0 | 0.0000 | 1/min
 |  | 1 | 0.0000 | 1/min
 |  | 2 | 0.0000 | 1/min
 |  | 3 | 0.0000 | 1/min
38 | Pos. velocity limit | 0 | 18600.0000 | 1/min
 |  | 1 | 5000.0000 | 1/min
 |  | 2 | 5000.0000 | 1/min
 |  | 3 | 5000.0000 | 1/min
39 | Neg. velocity limit | 0 | -18600.0000 | 1/min
 |  | 1 | -5000.0000 | 1/min
 |  | 2 | -5000.0000 | 1/min
 |  | 3 | -5000.0000 | 1/min
40 | Velocity feedback value | 0 | -0.0493 | 1/min
 |  | 1 | -0.0493 | 1/min
 |  | 2 | -0.0493 | 1/min
 |  | 3 | -0.0493 | 1/min
41 | Homing velocity | 0 | 100.0000 | 1/min
 |  | 1 | 100.0000 | 1/min
 |  | 2 | 100.0000 | 1/min
 |  | 3 | 100.0000 | 1/min
42 | Homing acceleration | 0 | 100.000 | U/ss
 |  | 1 | 100.000 | U/ss
 |  | 2 | 100.000 | U/ss
 |  | 3 | 100.000 | U/ss
43 | Velocity polarity | 0 | 0000 0000 0000 0000B
 |  | 1 | 0000 0000 0000 0000B
 |  | 2 | 0000 0000 0000 0000B
 |  | 3 | 0000 0000 0000 0000B
44 | Velocity data scaling type | 0 | 0000 0000 0000 0010B
 |  | 1 | 0000 0000 0000 0010B
 |  | 2 | 0000 0000 0000 0010B
 |  | 3 | 0000 0000 0000 0010B
45 | Velocity data scaling factor | 0 | 1
 |  | 1 | 1
 |  | 2 | 1
 |  | 3 | 1
46 | Velocity data scaling expone | 0 | -4
 |  | 1 | -4
 |  | 2 | -4
 |  | 3 | -4
47 | Position command value | 0 | -5300704 | incr.
 |  | 1 | -5300704 | incr.
 |  | 2 | -5300704 | incr.
 |  | 3 | -5300704 | incr.
49 | Positive position limit | 0 | 2147483647 | incr.
 |  | 1 | 2147483647 | incr.
 |  | 2 | 2147483647 | incr.
 |  | 3 | 2147483647 | incr.
50 | Negative position limit | 0 | -2147483648 | incr.
 |  | 1 | -2147483648 | incr.
 |  | 2 | -2147483648 | incr.
 |  | 3 | -2147483648 | incr.
51 | Position feedback value | 0 | -5300800 | incr.
 |  | 1 | -5300800 | incr.
 |  | 2 | -5300800 | incr.
 |  | 3 | -5300800 | incr.
52 | Home ref. position 1 | 0 | 0 | incr.
 |  | 1 | 0 | incr.
 |  | 2 | 0 | incr.
 |  | 3 | 0 | incr.
55 | Closed loop polar. par. | 0 | 0000 0000 0000 0000B
 |  | 1 | 0000 0000 0000 0000B
 |  | 2 | 0000 0000 0000 0000B
 |  | 3 | 0000 0000 0000 0000B
57 | In position window | 0 | 1000 | incr.
 |  | 1 | 1000 | incr.
 |  | 2 | 1000 | incr.
 |  | 3 | 1000 | incr.
76 | Position data scaling type | 0 | 0000 0000 0000 0000B
 |  | 1 | 0000 0000 0000 0000B
 |  | 2 | 0000 0000 0000 0000B
 |  | 3 | 0000 0000 0000 0000B
77 | Linear position data scaling | 0 | 1
 |  | 1 | 1
 |  | 2 | 1
 |  | 3 | 1
78 | Linear position data scaling | 0 | -7
 |  | 1 | -7
 |  | 2 | -7
 |  | 3 | -7
79 | Rotational position resoluti | 0 | 3600000 | incr.
 |  | 1 | 3600000 | incr.
 |  | 2 | 3600000 | incr.
 |  | 3 | 3600000 | incr.
80 | Torque command value | 0 | 0.0 | % MN | FSE - Can be written via CAN - Index 17
 |  | 1 | 10.0 | % MN
 |  | 2 | 10.0 | % MN
 |  | 3 | 10.0 | % MN
81 | Torque command value additiv | 0 | 0.0 | % MN
 |  | 1 | 0.0 | % MN
 |  | 2 | 0.0 | % MN
 |  | 3 | 0.0 | % MN
82 | Positive torque limit | 0 | 200.0 | % MN | FSE - Can be temporary written via CAN - Index 13
 |  | 1 | 120.0 | % MN
 |  | 2 | 120.0 | % MN
 |  | 3 | 120.0 | % MN
83 | Negative torque limit | 0 | -200.0 | % MN | FSE - Can be temporary written via CAN - Index 14
 |  | 1 | -120.0 | % MN
 |  | 2 | -120.0 | % MN
 |  | 3 | -120.0 | % MN
84 | Torque feedb.val | 0 | 0.0 | % MN | FSE - Can be read via CAN - Index 19
 |  | 1 | 0.0 | % MN
 |  | 2 | 0.0 | % MN
 |  | 3 | 0.0 | % MN
85 | Torque polarity | 0 | 0000 0000 0000 0000B
 |  | 1 | 0000 0000 0000 0000B
 |  | 2 | 0000 0000 0000 0000B
 |  | 3 | 0000 0000 0000 0000B
86 | Torque data scaling | 0 | 0000 0000 0000 0000B
 |  | 1 | 0000 0000 0000 0000B
 |  | 2 | 0000 0000 0000 0000B
 |  | 3 | 0000 0000 0000 0000B
89 | Transmit time MDT (T2) | 0 | 1.000 | ms
91 | Bip.veloc. limit | 0 | 18600.0000 | 1/min
 |  | 1 | 18600.0000 | 1/min
 |  | 2 | 18600.0000 | 1/min
 |  | 3 | 18600.0000 | 1/min
92 | Bip.torque limit | 0 | 120.0 | % MN
 |  | 1 | 120.0 | % MN
 |  | 2 | 120.0 | % MN
 |  | 3 | 120.0 | % MN
93 | Torque scaling factor | 0 | 1
 |  | 1 | 1
 |  | 2 | 1
 |  | 3 | 1
94 | Torque scaling exponent | 0 | -2
 |  | 1 | -2
 |  | 2 | -2
 |  | 3 | -2
95 | Diagnosis | 0 | 358600Systemdiagnose |  | FSE - Read only -
96 | Slave identifier (SKLN) | 0 | 0101H
 |  | 1 | 0101H
 |  | 2 | 0101H
 |  | 3 | 0101H
97 | Diag.mask st.class 2 | 0 | 0000 0000 0000 0000B
 |  | 1 | 0000 0000 0000 0000B
 |  | 2 | 0000 0000 0000 0000B
 |  | 3 | 0000 0000 0000 0000B
98 | Diag.mask st.class 3 | 0 | 0000 0000 0000 0000B
 |  | 1 | 0000 0000 0000 0000B
 |  | 2 | 0000 0000 0000 0000B
 |  | 3 | 0000 0000 0000 0000B
99 | Diag.reset st.class 1 | 0 | 0000 0000 0000 0000B
100 | Prop.gain speed control | 0 | 40 |  | FSE - Adjust with AIPEX - Optimization possible
 |  | 1 | 40
 |  | 2 | 40
 |  | 3 | 40
101 | Integr.act.time sp.ctrl | 0 | 20.0 | ms | FSE - Adjust with AIPEX - Optimization possible
 |  | 1 | 20.0 | ms
 |  | 2 | 20.0 | ms
 |  | 3 | 20.0 | ms
102 | Diff.time speed control | 0 | 0.0 | ms | FSE - Adjust with AIPEX - Optimization possible
 |  | 1 | 0.0 | ms
 |  | 2 | 0.0 | ms
 |  | 3 | 0.0 | ms
103 | Modulo value | 0 | 20000 | incr.
 |  | 1 | 20000 | incr.
 |  | 2 | 20000 | incr.
 |  | 3 | 20000 | incr.
104 | Position loop KV-factor | 0 | 20
 |  | 1 | 20
 |  | 2 | 20
 |  | 3 | 20
108 | Feedrate override | 0 | 100.00 | %
109 | Motor peak current | 0 | 105.000 | A | FSE - Adjust with AIPEX see motor data sheet -
 |  | 1 | 105.000 | A
 |  | 2 | 105.000 | A
 |  | 3 | 105.000 | A
110 | Inverter peak current | 0 | 107.200 | A | FSE - Read only -
111 | Motor nom. current | 0 | 41.000 | A | FSE - Adjust with AIPEX see motor data sheet -
 |  | 1 | 41.000 | A
 |  | 2 | 41.000 | A
 |  | 3 | 41.000 | A
112 | Inverter nom. current | 0 | 42.986 | A | FSE - Read only -
113 | Maximum speed | 0 | 16000.0000 | 1/min | FSE - Adjust with AIPEX see motor data sheet - Optimization possible max. 20000
 |  | 1 | 6000.0000 | 1/min
 |  | 2 | 6000.0000 | 1/min
 |  | 3 | 6000.0000 | 1/min
114 | Overload limit motor | 0 | 50.0 | % | FSE - Adjust with AIPEX - Start derating Firmware (torque limitation) Optimization possible
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

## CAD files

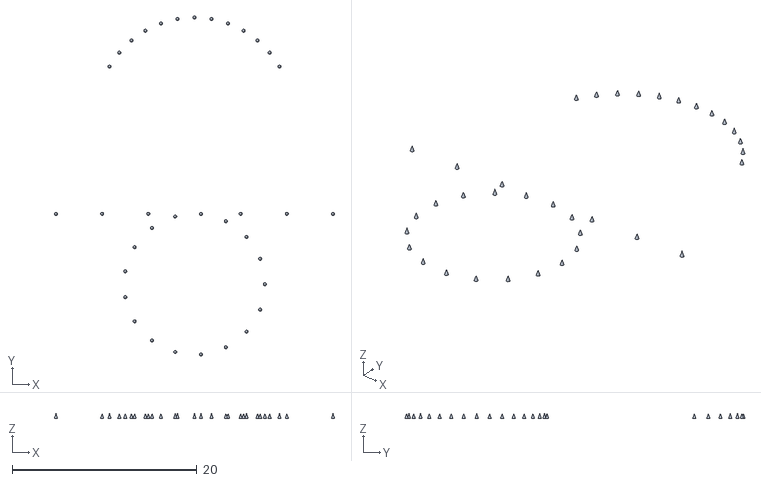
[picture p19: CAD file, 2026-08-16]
Controls/cones_left.stl
30.3 x 36.8 x 0.5

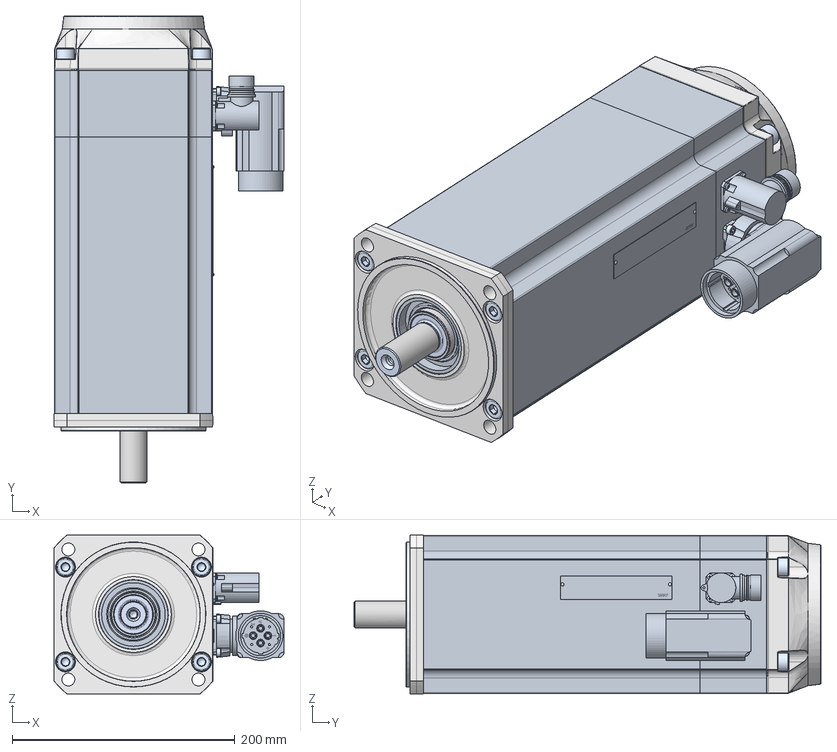
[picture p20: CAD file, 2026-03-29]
Documents/AMKmotion_DD_Stepfiles_V230828/DD7-43-12-xBO.stp
206.3 x 418.5 x 142.5 mm
Screw_DIN_7984_M10x20_v10.00 x 4
O-Ring x 3
109867_FE30
Screw_DIN_912_M4x12_v10.00 x 3
Screw_DIN_912_M4x10_v10.00 x 4
Schraube_DIN_EN_ISO_7045_M2.5x6_Z_v8.50 x 4
Screw_DIN_912_M5x35_v10.00 x 3
Screw_DIN_912_M4x8_v10.00 x 3
Screw_DIN_912_M10x80_v10.00 x 4
101829_eingebaut

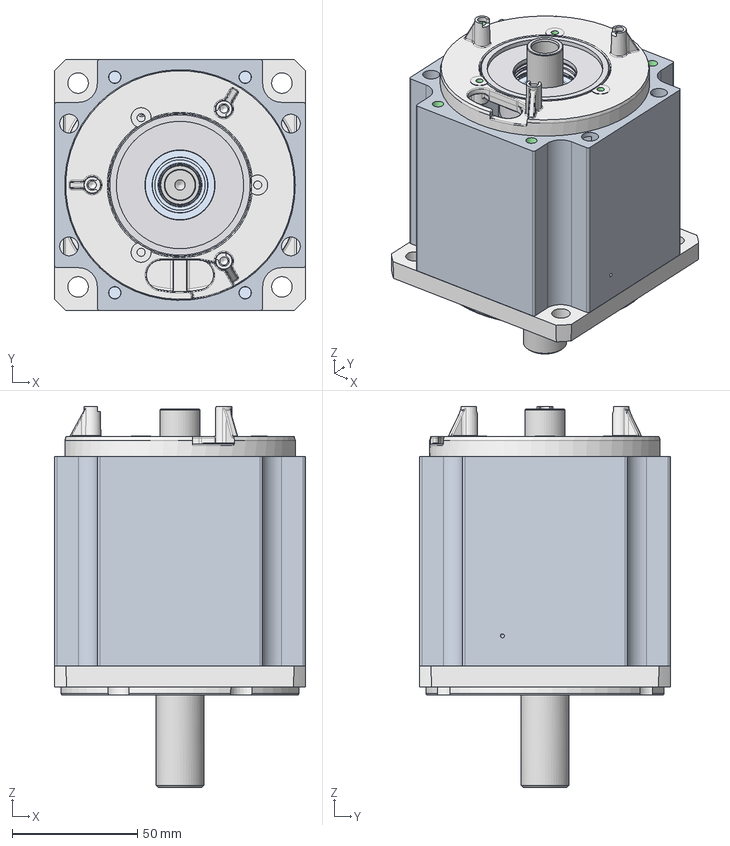
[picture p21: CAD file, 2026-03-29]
Documents/AMKmotion_DD_Stepfiles_V230828/DD5-4-10-xOO.stp
100.3 x 100.3 x 152.0 mm
Screw_DIN_6912_M6x20 x 4
Lager_DIN_625-1_6005_25x47x12
Sicherungsring_B_DIN_472__47x1,75_A
109391_FE30
Bearing_DIN_625_1_1989_6003_2RS_v10.00

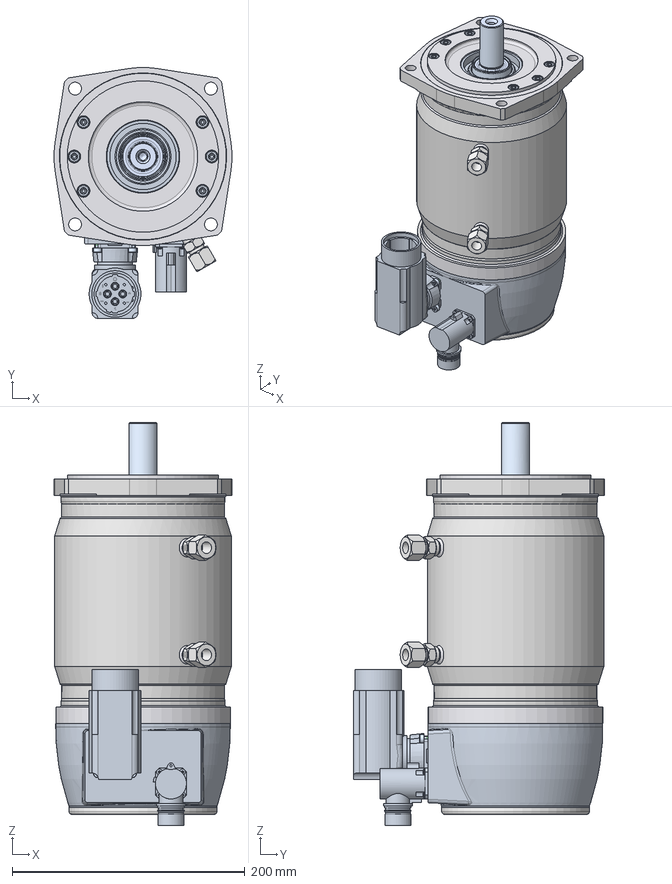
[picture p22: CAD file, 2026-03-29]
Documents/AMKmotion_DD_Stepfiles_V230828/DD7-50-10-xOO.stp
152.8 x 215.4 x 346.1 mm
Schraube_DIN_EN_ISO_7045_M_2,5x_8 x 4
Schraube_DIN_6912_M_6x_16 x 9
Schraube_DIN_912_M_6x_16 x 6
103577_Einbausituation
103608_M_5x_75 x 3
Screw_DIN_912_M4x12 x 4
Screw_DIN_912_M4x8 x 3

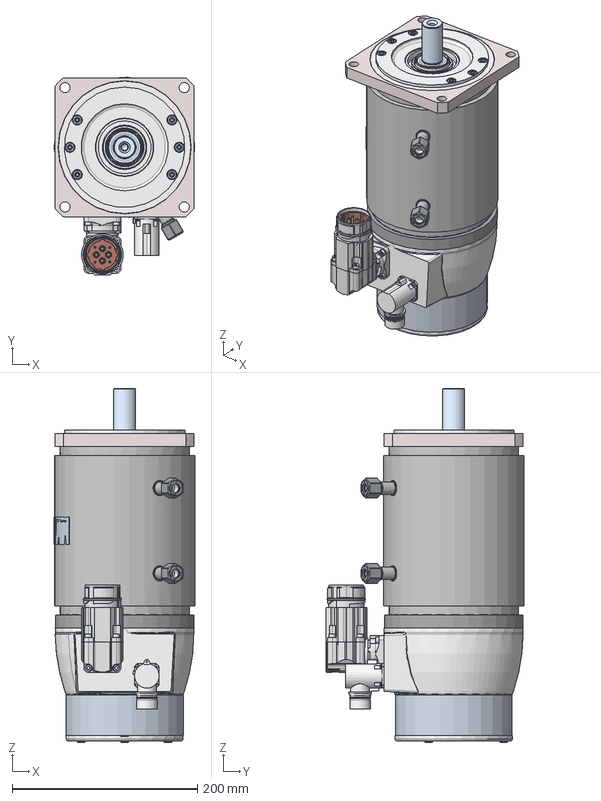
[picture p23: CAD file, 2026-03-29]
Documents/AMKmotion_DD_Stepfiles_V230828/DD7-50-10-xBO.stp
151.7 x 213.3 x 382.0 mm
113445_469_1.013_Kehlnaht 10_oa_3
113445_469_1.013_Kehlnaht 10_oa_4
113445_469_1.013_Kehlnaht 10_oa_5
113445_469_1.013_Kehlnaht 10_oa_6
113445_469_1.013_Kehlnaht 10_oa_7
113445_469_1.013_Kehlnaht 10_oa_8
113445_469_1.013_Kehlnaht 10_oa_9
113744_oa_10
113445_469_1.013_Kehlnaht 10_oa_11
113445_469_1.013_Kehlnaht 10_oa_12
113743_oa_13
113723_oa_14
Schraube_DIN_EN_ISO_7045_M_2,5x_8 x 4
103576_oa_17
101411_oa_18
101073_oa_19
Schraube_DIN_6912_M_6x_16_oa_20
Schraube_DIN_6912_M_6x_16_oa_21
Schraube_DIN_6912_M_6x_16_oa_22
Schraube_DIN_6912_M_6x_16_oa_23
Schraube_DIN_6912_M_6x_16_oa_24
Schraube_DIN_6912_M_6x_16_oa_25
111325_oa_27
103557_oa_28
15039_oa_30
1599_oa_31
1599_oa_32
109169_oa_33
1599_oa_34
109169_oa_35
109169_oa_36
Schraube_DIN_6912_M_6x_16_oa_38
Schraube_DIN_912_M_6x_16_oa_39
Schraube_DIN_6912_M_6x_16_oa_40
103577_Einbausituation_oa_41
Schraube_DIN_6912_M_6x_16_oa_42
Schraube_DIN_912_M_6x_16_oa_43
Schraube_DIN_912_M_6x_16_oa_44
Schraube_DIN_912_M_6x_16_oa_45
Schraube_DIN_912_M_6x_16_oa_46
Schraube_DIN_912_M_6x_16_oa_47
Screw_DIN_912_M4x12_oa_48
Screw_DIN_912_M4x12 x 3
111543_ﾘ151,4

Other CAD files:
Controls/bases/StraightLineControl/SLC1_ert_rtw/ert_main.obj
Controls/bases/StraightLineControl/SLC1_ert_rtw/SLC1.obj
Controls/cones_right.stl
Controls/tracks/cones_right.stl
Controls/bases/StraightLineControl/SLC1_ert_rtw/rt_nonfinite.obj

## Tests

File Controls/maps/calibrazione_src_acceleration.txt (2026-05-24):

=================================================
riduttore al 98%
=================================================

slip_Kp         = 90.0;   % [TUNABLE]
slip_Ki         = 65.0;    % [TUNABLE]
slip_Kd         = 2;    % [TUNABLE] 
slip_filt_N     = 110;     % Coefficiente filtro derivata (cutoff ≈ N/(2*pi*Ts) ≈ 318 Hz)
slip_ref        = 0.15;   % Slip ratio di riferimento [-]  [TUNABLE]  (ottimale ~0.10-0.20)
overslip_factor = 1.12;   % Fattore di sovraspinta per far innescare lo slip 
slip_up_sat     = 21; % Saturazione superiore PI [Nm]
slip_low_sat    = 0.0;    % Il PI non scende sotto 0 (Delta_T sempre positivo)
slip_bc_coeff   = 10;    % CoefficienteBack-Calculation PID [TUNABLE]
slip_V_min      = 1;    % Velocità sotto cui disabilitare TCS [m/s] 

5.158

slip_Kp         = 90.0;   % [TUNABLE]
slip_Ki         = 75.0;    % [TUNABLE]
slip_Kd         = 2;    % [TUNABLE] 
slip_filt_N     = 40;     % Coefficiente filtro derivata (cutoff ≈ N/(2*pi*Ts) ≈ 318 Hz)
slip_ref        = 0.15;   % Slip ratio di riferimento [-]  [TUNABLE]  (ottimale ~0.10-0.20)
overslip_factor = 1.12;   % Fattore di sovraspinta per far innescare lo slip 
slip_up_sat     = 21; % Saturazione superiore PI [Nm]
slip_low_sat    = 0.0;    % Il PI non scende sotto 0 (Delta_T sempre positivo)
slip_bc_coeff   = 10;    % CoefficienteBack-Calculation PID [TUNABLE]
slip_V_min      = 1;    % Velocità sotto cui disabilitare TCS [m/s] 

5.193

slip_Kp         = 85.0;   % [TUNABLE]
slip_Ki         = 120.0;    % [TUNABLE]
slip_Kd         = 1.4;    % [TUNABLE] 
slip_filt_N     = 30;     % Coefficiente filtro derivata (cutoff ≈ N/(2*pi*Ts) ≈ 318 Hz)
slip_ref        = 0.15;   % Slip ratio di riferimento [-]  [TUNABLE]  (ottimale ~0.10-0.20)
overslip_factor = 1.12;   % Fattore di sovraspinta per far innescare lo slip 
slip_up_sat     = 21; % Saturazione superiore PI [Nm]
slip_low_sat    = 0.0;    % Il PI non scende sotto 0 (Delta_T sempre positivo)
slip_bc_coeff   = 10;    % CoefficienteBack-Calculation PID [TUNABLE]
slip_V_min      = 1;    % Velocità sotto cui disabilitare TCS [m/s] 

5.137

slip_Kp         = 90.0;   % [TUNABLE]
slip_Ki         = 120.0;    % [TUNABLE]
slip_Kd         = 2;    % [TUNABLE] 
slip_filt_N     = 30;     % Coefficiente filtro derivata (cutoff ≈ N/(2*pi*Ts) ≈ 318 Hz)
slip_ref        = 0.15;   % Slip ratio di riferimento [-]  [TUNABLE]  (ottimale ~0.10-0.20)
overslip_factor = 1.12;   % Fattore di sovraspinta per far innescare lo slip 
slip_up_sat     = 21; % Saturazione superiore PI [Nm]
slip_low_sat    = 0.0;    % Il PI non scende sotto 0 (Delta_T sempre positivo)
slip_bc_coeff   = 10;    % CoefficienteBack-Calculation PID [TUNABLE]
slip_V_min      = 1;    % Velocità sotto cui disabilitare TCS [m/s] 

5.124

slip_Kp         = 90.0;   % [TUNABLE]
slip_Ki         = 70.0;    % [TUNABLE]
slip_Kd         = 2.5;    % [TUNABLE] 
slip_filt_N     = 30;     % Coefficiente filtro derivata (cutoff ≈ N/(2*pi*Ts) ≈ 318 Hz)
slip_ref        = 0.16;   % Slip ratio di riferimento [-]  [TUNABLE]  (ottimale ~0.10-0.20)
overslip_factor = 1.13;   % Fattore di sovraspinta per far innescare lo slip 
slip_up_sat     = 21; % Saturazione superiore PI [Nm]
slip_low_sat    = 0.0;    % Il PI non scende sotto 0 (Delta_T sempre positivo)
slip_bc_coeff   = 12;    % CoefficienteBack-Calculation PID [TUNABLE]
slip_V_min      = 1;    % Velocità sotto cui disabilitare TCS [m/s] 

5.286

--> PIU INSTABILI --> 

slip_Kp         = 180.0;   % [TUNABLE]
slip_Ki         = 120.0;    % [TUNABLE]
slip_Kd         = 2;    % [TUNABLE] 
slip_filt_N     = 30;     % Coefficiente filtro derivata (cutoff ≈ N/(2*pi*Ts) ≈ 318 Hz)
slip_ref        = 0.15;   % Slip ratio di riferimento [-]  [TUNABLE]  (ottimale ~0.10-0.20)
overslip_factor = 1.12;   % Fattore di sovraspinta per far innescare lo slip 
slip_up_sat     = 21; % Saturazione superiore PI [Nm]
slip_low_sat    = 0.0;    % Il PI non scende sotto 0 (Delta_T sempre positivo)
slip_bc_coeff   = 10;    % CoefficienteBack-Calculation PID [TUNABLE]
slip_V_min      = 1;    % Velocità sotto cui disabilitare TCS [m/s] 

4.892

slip_Kp         = 190.0;   % [TUNABLE]
slip_Ki         = 120.0;    % [TUNABLE]
slip_Kd         = 2;    % [TUNABLE] 
slip_filt_N     = 60;     % Coefficiente filtro derivata (cutoff ≈ N/(2*pi*Ts) ≈ 318 Hz)
slip_ref        = 0.15;   % Slip ratio di riferimento [-]  [TUNABLE]  (ottimale ~0.10-0.20)
overslip_factor = 1.12;   % Fattore di sovraspinta per far innescare lo slip 
slip_up_sat     = 21; % Saturazione superiore PI [Nm]
slip_low_sat    = 0.0;    % Il PI non scende sotto 0 (Delta_T sempre positivo)
slip_bc_coeff   = 10;    % CoefficienteBack-Calculation PID [TUNABLE]
slip_V_min      = 1;    % Velocità sotto cui disabilitare TCS [m/s] 

4.844

slip_Kp         = 190.0;   % [TUNABLE]
slip_Ki         = 130.0;    % [TUNABLE]
slip_Kd         = 5;    % [TUNABLE] 
slip_filt_N     = 40;     % Coefficiente filtro derivata (cutoff ≈ N/(2*pi*Ts) ≈ 318 Hz)
slip_ref        = 0.17;   % Slip ratio di riferimento [-]  [TUNABLE]  (ottimale ~0.10-0.20)
overslip_factor = 1.10;   % Fattore di sovraspinta per far innescare lo slip 
slip_up_sat     = 21; % Saturazione superiore PI [Nm]
slip_low_sat    = 0.0;    % Il PI non scende sotto 0 (Delta_T sempre positivo)
slip_bc_coeff   = 10;    % CoefficienteBack-Calculation PID [TUNABLE]
slip_V_min      = 1;    % Velocità sotto cui disabilitare TCS [m/s] 

4.818

slip_Kp         = 190.0;   % [TUNABLE]
slip_Ki         = 120.0;    % [TUNABLE]
slip_Kd         = 5;    % [TUNABLE] 
slip_filt_N     = 40;     % Coefficiente filtro derivata (cutoff ≈ N/(2*pi*Ts) ≈ 318 Hz)
slip_ref        = 0.17;   % Slip ratio di riferimento [-]  [TUNABLE]  (ottimale ~0.10-0.20)
overslip_factor = 1.10;   % Fattore di sovraspinta per far innescare lo slip 
slip_up_sat     = 21; % Saturazione superiore PI [Nm]
slip_low_sat    = 0.0;    % Il PI non scende sotto 0 (Delta_T sempre positivo)
slip_bc_coeff   = 10;    % CoefficienteBack-Calculation PID [TUNABLE]
slip_V_min      = 1;    % Velocità sotto cui disabilitare TCS [m/s] 

4.789

slip_Kp         = 220.0;   % [TUNABLE]
slip_Ki         = 120.0;    % [TUNABLE]
slip_Kd         = 4;    % [TUNABLE] 
slip_filt_N     = 40;     % Coefficiente filtro derivata (cutoff ≈ N/(2*pi*Ts) ≈ 318 Hz)
slip_ref        = 0.17;   % Slip ratio di riferimento [-]  [TUNABLE]  (ottimale ~0.10-0.20)
overslip_factor = 1.10;   % Fattore di sovraspinta per far innescare lo slip 
slip_up_sat     = 21; % Saturazione superiore PI [Nm]
slip_low_sat    = 0.0;    % Il PI non scende sotto 0 (Delta_T sempre positivo)
slip_bc_coeff   = 10;    % CoefficienteBack-Calculation PID [TUNABLE]
slip_V_min      = 1;    % Velocità sotto cui disabilitare TCS [m/s] 

4.765

slip_Kp         = 260.0;   % [TUNABLE]
slip_Ki         = 100.0;    % [TUNABLE]
slip_Kd         = 2;    % [TUNABLE] 
slip_filt_N     = 40;     % Coefficiente filtro derivata (cutoff ≈ N/(2*pi*Ts) ≈ 318 Hz)
slip_ref        = 0.17;   % Slip ratio di riferimento [-]  [TUNABLE]  (ottimale ~0.10-0.20)
overslip_factor = 1.10;   % Fattore di sovraspinta per far innescare lo slip 
slip_up_sat     = 21; % Saturazione superiore PI [Nm]
slip_low_sat    = 0.0;    % Il PI non scende sotto 0 (Delta_T sempre positivo)
slip_bc_coeff   = 10;    % CoefficienteBack-Calculation PID [TUNABLE]
slip_V_min      = 1;    % Velocità sotto cui disabilitare TCS [m/s] 

4.705

slip_Kp         = 195.0;   % [TUNABLE]
slip_Ki         = 120.0;    % [TUNABLE]
slip_Kd         = 3;    % [TUNABLE] 
slip_filt_N     = 25;     % Coefficiente filtro derivata (cutoff ≈ N/(2*pi*Ts) ≈ 318 Hz)
slip_ref        = 0.17;   % Slip ratio di riferimento [-]  [TUNABLE]  (ottimale ~0.10-0.20)
overslip_factor = 1.10;   % Fattore di sovraspinta per far innescare lo slip 
slip_up_sat     = 21; % Saturazione superiore PI [Nm]
slip_low_sat    = 0.0;    % Il PI non scende sotto 0 (Delta_T sempre positivo)
slip_bc_coeff   = 10;    % CoefficienteBack-Calculation PID [TUNABLE]
slip_V_min      = 1;    % Velocità sotto cui disabilitare TCS [m/s] 

4.942

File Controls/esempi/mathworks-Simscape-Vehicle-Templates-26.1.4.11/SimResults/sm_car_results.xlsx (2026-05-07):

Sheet: 2022a_250206_1736
Run | Preset | Body | SuspF | Tire | TirDyn | Drv | Trail | Mane | Solv | # Steps | Time | xFinal | yFinal | Figure | Pass | 06-Feb-2025 20:10:21
1 | 0 | HambaLG | dwb | MFEval | steady | f1Dr1D | None | WOT Braking | ode23t | 405 | 7.174 | 233.857 | 0.015 | figure | Pass | MATHWORKS-OL1OH
2 | 0 | HambaLG | dwb | MFEval | steady | f1Dr1D | None | Low Speed Steer | ode23t | 530 | 7.520 | 71.999 | -0.552 | figure | Pass | 9.12.0.2529717 (R2022a) Update 8
3 | 1 | HambaLG | dwb | MFEval | steady | f1D3Dr1D | None | WOT Braking | ode23t | 408 | 7.875 | 232.870 | -0.002 | figure | Pass | MF-Swift Version: 2306
4 | 1 | HambaLG | dwb | MFEval | steady | f1D3Dr1D | None | Low Speed Steer | ode23t | 522 | 8.068 | 71.689 | -0.548 | figure | Pass | v3p8 R22asrc driverPTBSVDBS
5 | 2 | HambaLG | dwb | MFEval | steady | fCVpCVr1D | None | WOT Braking | ode23t | 428 | 11.566 | 232.974 | 0.086 | figure | Pass
6 | 2 | HambaLG | dwb | MFEval | steady | fCVpCVr1D | None | Low Speed Steer | ode23t | 528 | 11.236 | 71.712 | -0.542 | figure | Pass
7 | 3 | HambaLG | dwb | MFEval | steady | fCVpCVflexr1D | None | WOT Braking | ode23t | 489 | 13.164 | 232.341 | -0.048 | figure | Pass
8 | 3 | HambaLG | dwb | MFEval | steady | fCVpCVflexr1D | None | Low Speed Steer | ode23t | 548 | 10.804 | 71.579 | -0.541 | figure | Pass
9 | 4 | HambaLG | dwb | MFEval | lintra | f1Dr1D | None | WOT Braking | ode23t | 1115 | 12.864 | 233.575 | 0.006 | figure | Pass
10 | 4 | HambaLG | dwb | MFEval | lintra | f1Dr1D | None | Low Speed Steer | ode23t | 1235 | 13.246 | 71.992 | -0.553 | figure | Pass
11 | 5 | HambaLG | dwb | MFEval | lintra | f1D3Dr1D | None | WOT Braking | ode23t | 1124 | 14.029 | 232.876 | 0.0002839514043 | figure | Pass
12 | 5 | HambaLG | dwb | MFEval | lintra | f1D3Dr1D | None | Low Speed Steer | ode23t | 1228 | 15.330 | 71.696 | -0.544 | figure | Pass
13 | 6 | HambaLG | dwb | MFEval | lintra | fCVpCVr1D | None | WOT Braking | ode23t | 1265 | 18.072 | 232.869 | 0.069 | figure | Pass
14 | 6 | HambaLG | dwb | MFEval | lintra | fCVpCVr1D | None | Low Speed Steer | ode23t | 1275 | 16.764 | 71.689 | -0.545 | figure | Pass
15 | 7 | HambaLG | dwb | MFEval | lintra | fCVpCVflexr1D | None | WOT Braking | ode23t | 1226 | 18.025 | 232.371 | 0.058 | figure | Pass
16 | 7 | HambaLG | dwb | MFEval | lintra | fCVpCVflexr1D | None | Low Speed Steer | ode23t | 1273 | 16.065 | 71.567 | -0.541 | figure | Pass
17 | 16 | HambaLG | dwa | MFEval | steady | f1Dr1D | None | WOT Braking | ode23t | 408 | 6.005 | 234.509 | -0.071 | figure | Pass
18 | 16 | HambaLG | dwa | MFEval | steady | f1Dr1D | None | Low Speed Steer | ode23t | 488 | 5.827 | 72.266 | -0.022 | figure | Pass
19 | 32 | HambaLG | S2LAF | MFEval | steady | f1Dr1D | None | WOT Braking | ode23t | 405 | 8.264 | 233.641 | 0.021 | figure | Pass
20 | 32 | HambaLG | S2LAF | MFEval | steady | f1Dr1D | None | Low Speed Steer | ode23t | 519 | 8.327 | 71.989 | -0.533 | figure | Pass
21 | 48 | HambaLG | S2LAR | MFEval | steady | f1Dr1D | None | WOT Braking | ode23t | 392 | 7.318 | 233.762 | -0.004 | figure | Pass
22 | 48 | HambaLG | S2LAR | MFEval | steady | f1Dr1D | None | Low Speed Steer | ode23t | 520 | 9.208 | 71.988 | -0.539 | figure | Pass
23 | 64 | HambaLG | 5S2LAF | MFEval | steady | f1Dr1D | None | WOT Braking | ode23t | 398 | 8.412 | 233.738 | 0.022 | figure | Pass
24 | 64 | HambaLG | 5S2LAF | MFEval | steady | f1Dr1D | None | Low Speed Steer | ode23t | 527 | 9.029 | 72.006 | -0.528 | figure | Pass
25 | 80 | HambaLG | 5S2LAR | MFEval | steady | f1Dr1D | None | WOT Braking | ode23t | 405 | 9.812 | 233.770 | -0.006 | figure | Pass
26 | 80 | HambaLG | 5S2LAR | MFEval | steady | f1Dr1D | None | Low Speed Steer | ode23t | 518 | 8.988 | 71.987 | -0.538 | figure | Pass
27 | 96 | HambaLG | 5CS2LAF | MFEval | steady | f1Dr1D | None | WOT Braking | ode23t | 415 | 6.751 | 235.611 | 0.031 | figure | Pass
28 | 96 | HambaLG | 5CS2LAF | MFEval | steady | f1Dr1D | None | Low Speed Steer | ode23t | 519 | 6.610 | 72.512 | -0.540 | figure | Pass
29 | 112 | HambaLG | 15DOF | MFEval | steady | f1Dr1D | None | WOT Braking | ode23t | 371 | 2.492 | 242.672 | 0.235 | figure | Pass
30 | 112 | HambaLG | 15DOF | MFEval | steady | f1Dr1D | None | Low Speed Steer | ode23t | 480 | 2.778 | 74.660 | -0.338 | figure | Pass
31 | 113 | HambaLG | 15DOF | MFEval | steady | f1D3Dr1D | None | WOT Braking | ode23t | 366 | 2.923 | 241.499 | 0.229 | figure | Pass
32 | 113 | HambaLG | 15DOF | MFEval | steady | f1D3Dr1D | None | Low Speed Steer | ode23t | 487 | 3.300 | 74.346 | -0.334 | figure | Pass
33 | 114 | HambaLG | 15DOF | MFEval | steady | fCVpCVr1D | None | WOT Braking | ode23t | 382 | 3.147 | 241.614 | 0.230 | figure | Pass
34 | 114 | HambaLG | 15DOF | MFEval | steady | fCVpCVr1D | None | Low Speed Steer | ode23t | 482 | 3.226 | 74.351 | -0.334 | figure | Pass
35 | 115 | HambaLG | 15DOF | MFEval | steady | fCVpCVflexr1D | None | WOT Braking | ode23t | 394 | 3.163 | 241.173 | 0.228 | figure | Pass
36 | 115 | HambaLG | 15DOF | MFEval | steady | fCVpCVflexr1D | None | Low Speed Steer | ode23t | 505 | 3.402 | 74.209 | -0.332 | figure | Pass
37 | 116 | HambaLG | 15DOF | MFEval | lintra | f1Dr1D | None | WOT Braking | ode23t | 943 | 4.567 | 242.631 | 0.233 | figure | Pass
38 | 116 | HambaLG | 15DOF | MFEval | lintra | f1Dr1D | None | Low Speed Steer | ode23t | 1060 | 5.045 | 74.660 | -0.340 | figure | Pass
39 | 117 | HambaLG | 15DOF | MFEval | lintra | f1D3Dr1D | None | WOT Braking | ode23t | 951 | 5.189 | 241.561 | 0.230 | figure | Pass
40 | 117 | HambaLG | 15DOF | MFEval | lintra | f1D3Dr1D | None | Low Speed Steer | ode23t | 1068 | 5.230 | 74.351 | -0.337 | figure | Pass
41 | 118 | HambaLG | 15DOF | MFEval | lintra | fCVpCVr1D | None | WOT Braking | ode23t | 941 | 5.266 | 241.368 | 0.230 | figure | Pass
42 | 118 | HambaLG | 15DOF | MFEval | lintra | fCVpCVr1D | None | Low Speed Steer | ode23t | 1055 | 5.946 | 74.351 | -0.334 | figure | Pass
43 | 119 | HambaLG | 15DOF | MFEval | lintra | fCVpCVflexr1D | None | WOT Braking | ode23t | 964 | 5.325 | 241.113 | 0.230 | figure | Pass
44 | 119 | HambaLG | 15DOF | MFEval | lintra | fCVpCVflexr1D | None | Low Speed Steer | ode23t | 1081 | 6.021 | 74.201 | -0.332 | figure | Pass
45 | 128 | HambaLG | dwb | MFMbody | steady | oneShaft | None | WOT Braking | ode23t | 321 | 5.511 | 100.602 | -0.016 | figure | Pass
46 | 128 | HambaLG | dwb | MFMbody | steady | oneShaft | None | Low Speed Steer | ode23t | 438 | 6.953 | 37.245 | -0.134 | figure | Pass
47 | 129 | HambaLG | dwb | MFMbody | steady | fCVrCV | None | WOT Braking | ode23t | 343 | 6.762 | 232.733 | 0.075 | figure | Pass
48 | 129 | HambaLG | dwb | MFMbody | steady | fCVrCV | None | Low Speed Steer | ode23t | 488 | 8.186 | 71.613 | -0.541 | figure | Pass
49 | 130 | HambaLG | dwb | MFEval | steady | 1D3DABS | None | WOT Braking | ode23t | 798 | 23.988 | 219.867 | -1.471 | figure | Pass
50 | 130 | HambaLG | dwb | MFEval | steady | 1D3DABS | None | Low Speed Steer | ode23t | 792 | 21.834 | 69.507 | -0.552 | figure | Pass
51 | 131 | HambaLG | dwb | MFMbody | steady | sprFnl | None | WOT Braking | ode23t | 347 | 4.685 | 232.889 | -0.033 | figure | Pass
52 | 131 | HambaLG | dwb | MFMbody | steady | sprFnl | None | Low Speed Steer | ode23t | 487 | 5.776 | 71.701 | -0.553 | figure | Pass
53 | 132 | HambaLG | dwb | MFMbody | steady | sprconRnl | None | WOT Braking | ode23t | 342 | 4.660 | 232.767 | 0.001 | figure | Pass
54 | 132 | HambaLG | dwb | MFMbody | steady | sprconRnl | None | Low Speed Steer | ode23t | 473 | 5.450 | 71.717 | -0.547 | figure | Pass
55 | 133 | HambaLG | dwb | MFMbody | steady | sprLin | None | WOT Braking | ode23t | 346 | 4.317 | 232.817 | 0.0002238580841 | figure | Pass
56 | 133 | HambaLG | dwb | MFMbody | steady | sprLin | None | Low Speed Steer | ode23t | 489 | 5.545 | 71.712 | -0.544 | figure | Pass
57 | 134 | HambaLG | dwb | MFMbody | steady | daminRnl | None | WOT Braking | ode23t | 352 | 4.517 | 232.832 | 0.001 | figure | Pass
58 | 134 | HambaLG | dwb | MFMbody | steady | daminRnl | None | Low Speed Steer | ode23t | 490 | 5.556 | 71.715 | -0.545 | figure | Pass
59 | 135 | HambaLG | dwb | MFMbody | steady | damconFnl | None | WOT Braking | ode23t | 358 | 5.011 | 232.768 | 0.001 | figure | Pass
60 | 135 | HambaLG | dwb | MFMbody | steady | damconFnl | None | Low Speed Steer | ode23t | 497 | 5.296 | 71.706 | -0.539 | figure | Pass
61 | 136 | HambaLG | dwb | MFMbody | steady | CVCVp1D | None | WOT Braking | ode23t | 376 | 5.493 | 232.851 | 0.066 | figure | Pass
62 | 136 | HambaLG | dwb | MFMbody | steady | CVCVp1D | None | Low Speed Steer | ode23t | 502 | 6.608 | 71.702 | -0.542 | figure | Pass
63 | 137 | HambaLG | dwb | MFMbody | steady | f1Dr1D | None | WOT Braking | ode23t | 329 | 4.091 | 233.783 | 0.149 | figure | Pass
64 | 137 | HambaLG | dwb | MFMbody | steady | f1Dr1D | None | Low Speed Steer | ode23t | 479 | 4.700 | 71.984 | -0.526 | figure | Pass
65 | 138 | HambaLG | dwb | MFMbody | steady | f1Dr1D | None | WOT Braking | ode23t | 328 | 5.868 | 233.674 | 0.151 | figure | Pass
66 | 138 | HambaLG | dwb | MFMbody | steady | f1Dr1D | None | Low Speed Steer | ode23t | 498 | 6.607 | 71.873 | -0.845 | figure | Pass
67 | 139 | Hamba | dwb | MFEval | steady | fCVpCVr1D | None | WOT Braking | ode23t | 662 | 25.313 | 411.152 | 1.536 | figure | Pass
68 | 139 | Hamba | dwb | MFEval | steady | fCVpCVr1D | None | Low Speed Steer | ode23t | 610 | 14.572 | 156.997 | -0.559 | figure | Pass
69 | 141 | Hamba | dwb | MFEval | lintra | fCVpCVr1D | None | WOT Braking | ode23t | 1945 | 36.275 | 411.265 | 1.560 | figure | Pass
70 | 141 | Hamba | dwb | MFEval | lintra | fCVpCVr1D | None | Low Speed Steer | ode23t | 1803 | 23.265 | 157.082 | -0.564 | figure | Pass
71 | 143 | Makhulu | dwb | MFEval2x | steady | fCVpCVr1D | None | WOT Braking | ode23t | 363 | 22.092 | 96.637 | -0.040 | figure | Pass
72 | 143 | Makhulu | dwb | MFEval2x | steady | fCVpCVr1D | None | Low Speed Steer | ode23t | 475 | 24.694 | 25.157 | -0.055 | figure | Pass
73 | 144 | Makhulu | dwb | MFEval | steady | fCVpCVr1D | None | WOT Braking | ode23t | 362 | 15.939 | 115.002 | 0.532 | figure | Pass
74 | 144 | Makhulu | dwb | MFEval | steady | fCVpCVr1D | None | Low Speed Steer | ode23t | 485 | 17.313 | 35.847 | -0.035 | figure | Pass
75 | 147 | Hamba | dwb | CFL | steady | fCVpCVr1D | None | WOT Braking | ode23t | 2641 | 28.193 | 401.355 | -62.324 | figure | Pass
76 | 147 | Hamba | dwb | CFL | steady | fCVpCVr1D | None | Low Speed Steer | ode23t | 1322 | 17.162 | 155.225 | -2.685 | figure | Pass
77 | 183 | Achilles | dwpull | MFEval | steady | f1Dr1D | None | WOT Braking | ode23t | 1114 | 30.565 | 184.760 | -0.104 | figure | Pass
78 | 183 | Achilles | dwpull | MFEval | steady | f1Dr1D | None | Low Speed Steer | ode23t | 1368 | 35.009 | 57.828 | 0.063 | figure | Pass
79 | 8 | HambaLG | dwb | MFSwift | steady | f1Dr1D | None | WOT Braking | ode23t | 375 | 9.845 | 233.870 | 0.009 | figure | Pass
80 | 8 | HambaLG | dwb | MFSwift | steady | f1Dr1D | None | Low Speed Steer | ode23t | 547 | 12.532 | 71.998 | -0.552 | figure | Pass
81 | 9 | HambaLG | dwb | MFSwift | steady | f1D3Dr1D | None | WOT Braking | ode23t | 392 | 11.821 | 232.841 | 0.001 | figure | Pass
82 | 9 | HambaLG | dwb | MFSwift | steady | f1D3Dr1D | None | Low Speed Steer | ode23t | 562 | 14.778 | 71.706 | -0.542 | figure | Pass
83 | 10 | HambaLG | dwb | MFSwift | steady | fCVpCVr1D | None | WOT Braking | ode23t | 392 | 12.770 | 232.548 | 0.067 | figure | Pass
84 | 10 | HambaLG | dwb | MFSwift | steady | fCVpCVr1D | None | Low Speed Steer | ode23t | 546 | 16.125 | 71.702 | -0.543 | figure | Pass
85 | 11 | HambaLG | dwb | MFSwift | steady | fCVpCVflexr1D | None | WOT Braking | ode23t | 423 | 14.895 | 232.155 | 0.067 | figure | Pass
86 | 11 | HambaLG | dwb | MFSwift | steady | fCVpCVflexr1D | None | Low Speed Steer | ode23t | 560 | 17.489 | 71.572 | -0.536 | figure | Pass
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

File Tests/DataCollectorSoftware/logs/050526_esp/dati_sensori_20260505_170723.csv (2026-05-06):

Time_ms | TempMotor | TempInverter | TempIGBT | Voltage | Speed | Iq | Id | TorqueMotor | PedalPerc | InvState | ErrCode | StatusWord | ErrInfo1 | PhaseU_mA | PhaseV_mA | PhaseW_mA | Power_W | TorqueSetpoint | TorqueLimitDyn
ESP32 Bridge connesso
0 | 22.4 | 15.6 | 15.6 | 0 | 0 | 0.1 | 0.0 | 0.0 | 0 | 2 | 0 | 37120 | 0 | -5 | -1 | 11 | 0 | 0 | 0 | 17.47 | 17.20 | -51.57
0 | 22.4 | 15.6 | 15.6 | 0 | 0 | 0.1 | -0.0 | -0.0 | 0 | 2 | 0 | 37120 | 0 | -5 | 9 | -3 | 0 | 0 | 0 | 17.91 | 17.05 | -52.17
0 | 22.4 | 15.6 | 15.6 | 0 | 0 | 0.1 | -0.0 | 0.0 | 0 | 2 | 0 | 37120 | 0 | -2 | 8 | -3 | 0 | 0 | 0 | 16.75 | 17.05 | -65.42
0 | 22.4 | 15.6 | 15.6 | 0 | 0 | 0.1 | -0.0 | -0.0 | 0 | 2 | 0 | 37120 | 0 | -2 | -5 | 8 | 0 | 0 | 0 | 17.15 | 17.47 | -52.99
0 | 22.4 | 15.6 | 15.6 | 9 | 0 | 0.1 | 0.0 | 0.0 | 0 | 4 | 0 | 63744 | 0 | 3 | -5 | 8 | 0 | 0 | 0 | 17.47 | 17.39 | -51.57
500 | 22.4 | 15.6 | 15.6 | 9 | 0 | 0.1 | 0.0 | -0.0 | 0 | 4 | 0 | 63744 | 0 | -5 | -4 | 8 | 0 | 0 | 0 | 16.07 | 17.56 | -54.08
1000 | 22.4 | 15.6 | 15.6 | 9 | 0 | 0.1 | -0.0 | 0.0 | 0 | 4 | 0 | 63744 | 0 | 0 | -2 | 2 | 0 | 0 | 0 | 17.10 | 15.75 | -63.66
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

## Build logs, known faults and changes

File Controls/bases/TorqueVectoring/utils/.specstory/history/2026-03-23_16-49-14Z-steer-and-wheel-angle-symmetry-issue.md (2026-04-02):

<!-- Generated by SpecStory, Markdown v2.1.0 -->

# 2026-03-23 16:49:28Z

<!-- copilotide Session c7c23b6c-f375-4e6d-88b5-9bfc5035513f (2026-03-23 16:49:28Z) -->

_**User (2026-03-23 16:49:28Z)**_

Steer angle: -90.00 degrees, Wheel angle: -0.26
Steer angle: -80.00 degrees, Wheel angle: -0.22
Steer angle: -70.00 degrees, Wheel angle: -0.19
Steer angle: -60.00 degrees, Wheel angle: -0.17
Steer angle: -50.00 degrees, Wheel angle: -0.13
Steer angle: -40.00 degrees, Wheel angle: -0.10
Steer angle: -30.00 degrees, Wheel angle: -0.08
Steer angle: -20.00 degrees, Wheel angle: -0.04
Steer angle: -10.00 degrees, Wheel angle: 0.00
Steer angle: 0.00 degrees, Wheel angle: 0.00
Steer angle: 10.00 degrees, Wheel angle: 0.00
Steer angle: 20.00 degrees, Wheel angle: 0.06
Steer angle: 30.00 degrees, Wheel angle: 0.10
Steer angle: 40.00 degrees, Wheel angle: 0.11
Steer angle: 50.00 degrees, Wheel angle: 0.15
Steer angle: 60.00 degrees, Wheel angle: 0.19
Steer angle: 70.00 degrees, Wheel angle: 0.20
Steer angle: 80.00 degrees, Wheel angle: 0.24
Steer angle: 90.00 degrees, Wheel angle: 0.28

Questo codice fatto cosi pero non è simmetrico...

---

_**Agent (copilot/auto)**_

Hai ragione: dai valori che hai riportato la curva non è speculare tra lato sinistro e destro. Controllo subito il file 

---

_**User (2026-03-23 16:52:27Z)**_

Ma valori 0.xx di wheel angle cosa vogliono dire? Perche sono valori cosi bassi?

---

_**Agent (copilot/auto)**_

Ottima domanda: quei valori 0.xx non sono angoli in gradi, sono il risultato della tangente, quindi un valore adimensionale.

Nel tuo codice succede questo:
- In [Steer2Wheel.c](Steer2Wheel.c#L8) converti lo sterzo in un angolo ruota in gradi:
  wheel_angle_deg = steer_angle_deg * STEER_RATIO
- In [Steer2Wheel.c](Steer2Wheel.c#L18) fai:
  tand = tanf(center_deg * DEG_TO_RAD)
- In [Steer2Wheel.c](Steer2Wheel.c#L20) ritorni tand, non center_deg.

Perché sono piccoli?
- Con STEER_RATIO = 30/180 = 1/6 in [Steer2Wheel.c](Steer2Wheel.c#L4), anche a 90° volante ottieni solo ~15° ruota.
- tan(15°) ≈ 0.268, quindi è normale vedere numeri tipo 0.20, 0.28.
- Vicino a 0°, tan(θ) ≈ θ (in radianti), quindi i valori restano bassi.

Quindi:
- Se vuoi stampare angolo ruota in gradi, devi stampare center_deg (con segno), non tan.
- Se invece ti serve per dinamica veicolo (modelli bici), tan(δ) è spesso proprio il valore giusto da usare.

Se vuoi, posso modificarti subito il file per stampare entrambe le cose: angolo ruota in gradi e tan(angle), così è chiarissimo.

---

_**User (2026-03-23 16:54:28Z)**_

ma allora wheel_angle cosa vuol dire? Fai in modo che la funzione ritorni sia tand che l'angolo ruote

---

_**Agent (copilot/auto)**_

Chiaro: aggiorno subito la funzione in modo che ritorni entrambi i risultati, cioè angolo ruota in gradi e tangente. Prima leggo il file corrente per allinearmi alle ultime modifiche.

---

_**User (2026-03-23 16:55:31Z)**_

No non aggiungere altre struct

---

_**Agent (copilot/auto)**_

<think><details><summary>Thought Process</summary>
Perfetto, niente struct: converto la funzione a output tramite parametri puntatore, così ottieni sia angolo ruota sia tangente senza introdurre nuovi tipi. Leggo il file e applico la modifica minimale.

Procedo ora a rimuovere la struct e ad aggiornare chiamata e stampa nel `main` mantenendo identica logica di calcolo.
</details></think>

_**Agent (copilot/auto)**_

<tool-use data-tool-type="read" data-tool-name="read_file"><details>
<summary>Tool use: **read_file**</summary>

**Input:**

- endLine: `260`
- filePath: `e:\UNIVPM\PolimarcheRacingTeam\EV-POWERTRAIN-CONTROL\ev-powertrain-control\Controls\TV\utils\Steer2Wheel.c`
- startLine: `1`

</details></tool-use>

_**Agent (copilot/auto)**_

<tool-use data-tool-type="write" data-tool-name="apply_patch"><details>
<summary>Tool use: **apply_patch**</summary>

**Input:**

- explanation: `Remove struct and return both outputs via pointer parameters as requested.`
- input:

```
*** Begin Patch
*** Update File: e:\UNIVPM\PolimarcheRacingTeam\EV-POWERTRAIN-CONTROL\ev-powertrain-control\Controls\TV\utils\Steer2Wheel.c
@@
 #define STEER_RATIO (30.0f / 180.0f) //rapporto volante-ruota
 #define DEAD_ZONE_DEG 2.0f //TV disattivato sotto la soglia
 #define DEG_TO_RAD (3.14159265f / 180.0f)
 
-typedef struct {
-    float wheel_angle_deg;
-    float tan_delta;
-} WheelConversion;
-
-WheelConversion steer2wheel(float steer_angle_deg) {
-    WheelConversion out;
+void steer2wheel(float steer_angle_deg, float *wheel_angle_deg_out, float *tan_delta_out) {
     float wheel_angle_deg = steer_angle_deg * STEER_RATIO; 
 
     if (fabsf(wheel_angle_deg) < DEAD_ZONE_DEG) {
-        out.wheel_angle_deg = 0.0f;
-        out.tan_delta = 0.0f;
-        return out; // TV disattivato
+        *wheel_angle_deg_out = 0.0f;
+        *tan_delta_out = 0.0f;
+        return; // TV disattivato
     }
@@
-    out.wheel_angle_deg = copysignf(center_deg, wheel_angle_deg);
-    out.tan_delta = copysignf(tand, wheel_angle_deg);
-    return out;
+    *wheel_angle_deg_out = copysignf(center_deg, wheel_angle_deg);
+    *tan_delta_out = copysignf(tand, wheel_angle_deg);
 }
 
 int main() {
     for (float steer_angle = -90.0f; steer_angle <= 90.0f; steer_angle += 10.0f) {
-        WheelConversion result = steer2wheel(steer_angle);
+        float wheel_angle_deg;
+        float tan_delta;
+        steer2wheel(steer_angle, &wheel_angle_deg, &tan_delta);
         printf("Steer angle: %.2f deg, Wheel angle: %.2f deg, tan(delta): %.2f\n",
                steer_angle,
-               result.wheel_angle_deg,
-               result.tan_delta);
+               wheel_angle_deg,
+               tan_delta);
     }   
     return 0;
 }
*** End Patch
```

</details></tool-use>

_**Agent (copilot/auto)**_

Perfetto, niente struct: converto la funzione a output tramite parametri puntatore, così ottieni sia angolo ruota sia tangente senza introdurre nuovi tipi. Leggo il file e applico la modifica minimale.

---

_**User (2026-03-23 16:58:26Z)**_

Però aspetta, io potrei avere il volante girato anche per valori diversi di 10°.
Voglio che venga rispettato "Il
sistema tratta poi la tangente di δ come costante, quinid vengono definiti degli
intervalli ogni grado di sterzo dove la tangente ha valore costante (ad esempio
se le ruote hanno δ che va da 0 a 30 n intervalli del tipo 2-3,3-4,4-5,...29-30)."

---

_**Agent (copilot/auto)**_

<think><details><summary>Thought Process</summary>
Hai ragione: il punto è discretizzare su intervalli di 1° della ruota, indipendentemente dal passo del volante. Aggiorno il codice in modo esplicito su bin [n, n+1) e poi ti lascio anche un test nel main con valori non multipli di 10°.

Applico ora la modifica minimale: uso `floorf` per definire chiaramente i bin da 1° e aggiorno il `main` per mostrare anche ingressi non multipli di 10°.
</details></think>

_**Agent (copilot/auto)**_

<tool-use data-tool-type="read" data-tool-name="read_file"><details>
<summary>Tool use: **read_file**</summary>

**Input:**

- endLine: `260`
- filePath: `e:\UNIVPM\PolimarcheRacingTeam\EV-POWERTRAIN-CONTROL\ev-powertrain-control\Controls\TV\utils\Steer2Wheel.c`
- startLine: `1`

</details></tool-use>

_**Agent (copilot/auto)**_

<tool-use data-tool-type="write" data-tool-name="apply_patch"><details>
<summary>Tool use: **apply_patch**</summary>

**Input:**

- explanation: `Make 1-degree interval quantization explicit and demonstrate non-10-degree steer inputs in main.`
- input:

```
*** Begin Patch
*** Update File: e:\UNIVPM\PolimarcheRacingTeam\EV-POWERTRAIN-CONTROL\ev-powertrain-control\Controls\TV\utils\Steer2Wheel.c
@@
 void steer2wheel(float steer_angle_deg, float *wheel_angle_deg_out, float *tan_delta_out) {
     float wheel_angle_deg = steer_angle_deg * STEER_RATIO; 
+    float abs_wheel_angle_deg = fabsf(wheel_angle_deg);
 
-    if (fabsf(wheel_angle_deg) < DEAD_ZONE_DEG) {
+    if (abs_wheel_angle_deg < DEAD_ZONE_DEG) {
         *wheel_angle_deg_out = 0.0f;
         *tan_delta_out = 0.0f;
         return; // TV disattivato
     }
 
-    int interval = (int)fabsf(wheel_angle_deg);
-
-    float center_deg = (float)interval + 0.5f; // centro dell'intervallo
+    // Intervalli di 1 grado: [n, n+1), tangente costante nel centro dell'intervallo.
+    float interval_start_deg = floorf(abs_wheel_angle_deg);
+    float center_deg = interval_start_deg + 0.5f;
     float tand = tanf(center_deg * DEG_TO_RAD);
@@
 int main() {
-    for (float steer_angle = -90.0f; steer_angle <= 90.0f; steer_angle += 10.0f) {
+    for (float steer_angle = -90.0f; steer_angle <= 90.0f; steer_angle += 7.0f) {
         float wheel_angle_deg;
         float tan_delta;
         steer2wheel(steer_angle, &wheel_angle_deg, &tan_delta);
*** End Patch
```

</details></tool-use>

_**Agent (copilot/auto)**_

Hai ragione: il punto è discretizzare su intervalli di 1° della ruota, indipendentemente dal passo del volante. Aggiorno il codice in modo esplicito su bin [n, n+1) e poi ti lascio anche un test nel main con valori non multipli di 10°.

---

_**User (2026-03-23 17:00:04Z)**_

Quindi qual'è la sensibilità del volante?

---

_**Agent (copilot/auto)**_

La sensibilità impostata nel tuo codice è:

1. Sensibilità volante → ruota: 30/180 = 1/6
2. Quindi: 1° ruota ogni 6° volante
3. In forma equivalente: 0.1667° ruota per ogni 1° volante

Tradotto:
- Se giri il volante di 60°, la ruota vale circa 10°.
- Se giri il volante di 90°, la ruota vale circa 15°.

Attenzione però a due effetti che hai aggiunto:
1. Dead zone: sotto circa 12° volante (perché 12 × 1/6 = 2° ruota) l’uscita viene forzata a zero.
2. Quantizzazione a 1° ruota: la risposta cambia a gradini da 1° ruota, cioè circa ogni 6° volante.

---

_**User (2026-03-23 17:07:21Z)**_

Aggiungi allora una simulazione di conversione: io conosco il valore di sterzo del volante tramite ADC da un potenziometro rotativo, ma (da come penso) il volante dritto vuol dire che ho una tensione a metà. Definisci i vari valori per poter far funzionare tutto, per esempio anche il range, sensibilità ....

_**User (2026-03-23 17:07:52Z)**_

@agent Try Again

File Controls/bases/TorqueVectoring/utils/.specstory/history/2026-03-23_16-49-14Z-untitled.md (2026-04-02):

<!-- Generated by SpecStory, Markdown v2.1.0 -->

# 2026-03-23 16:49:14Z

<!-- copilotide Session c7c23b6c-f375-4e6d-88b5-9bfc5035513f (2026-03-23 16:49:14Z) -->

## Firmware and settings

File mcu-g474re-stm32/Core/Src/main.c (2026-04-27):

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
/* Includes ------------------------------------------------------------------*/
#include "main.h"

/* USER CODE BEGIN Includes */
#include <stdio.h>
#include <stdarg.h>
#include <string.h>
/* USER CODE END Includes */

ADC_HandleTypeDef hadc1;
DMA_HandleTypeDef hdma_adc1;

FDCAN_HandleTypeDef hfdcan1;
FDCAN_HandleTypeDef hfdcan2;

IWDG_HandleTypeDef hiwdg;

UART_HandleTypeDef hlpuart1;
DMA_HandleTypeDef hdma_lpuart1_tx;

TIM_HandleTypeDef htim2;
DMA_HandleTypeDef hdma_tim2_ch2;
DMA_HandleTypeDef hdma_tim2_ch3;

/* USER CODE BEGIN PV */

/* -----------------------------------------------------------------------
 *  ADC – 4 canali DMA continuo (circolare)
 *  Buffer: [0]=PB14/CH5  [1]=PB12/CH11  [2]=PB1/CH12  [3]=PB11/CH14
 * --------------------------------------------------------------------- */
#define ADC_NUM_CH   4u
volatile uint16_t g_adc[ADC_NUM_CH];          /* raw 12-bit ADC values  */

/* -----------------------------------------------------------------------
 *  LPUART1 – debug su ST-Link VCP via DMA
 *  Pattern identico a Serial.c (buffer DMA + flag busy + TxCplt callback)
 * --------------------------------------------------------------------- */
#define LPUART_BUF_SIZE   128u
static char      g_lpuart_buf[LPUART_BUF_SIZE];
volatile uint8_t g_lpuart_busy = 0;

/* -----------------------------------------------------------------------
 *  FDCAN  (CAN1 = PA11/PA12 @ 500 kbps,  CAN2 = PB5/PB6 @ 500 kbps)
 *
 *  NOTA: la G474RE NON bypassa automaticamente un bus CAN assente.
 *  HAL_FDCAN_Init / Start riescono sempre; la trasmissione fallirà
 *  silenziosamente se non c'è nessun altro nodo ad ACK-are.
 *  Con AutoRetransmission=DISABLE (già impostato dal CubeMX) il TX
 *  viene tentato una sola volta e non si innesca il bus-off loop.
 *  Il bus-off viene comunque rilevato e recuperato nel main loop.
 *  Per test senza hardware CAN → cambiare Mode in
 *  FDCAN_MODE_INTERNAL_LOOPBACK nel .ioc e rigenerare.
 * --------------------------------------------------------------------- */
volatile uint8_t       g_btn_tx_req  = 0;     /* richiesta TX da pulsante */
FDCAN_RxHeaderTypeDef  g_can_rx_hdr;
uint8_t                g_can_rx_data[8];
volatile uint32_t      g_can1_rx_cnt = 0;
volatile uint32_t      g_can2_rx_cnt = 0;

/* -----------------------------------------------------------------------
 *  Speed sensors – TIM2 Input Capture DMA circolare
 *  PB3  → TIM2_CH2 → ruota 1
 *  PB10 → TIM2_CH3 → ruota 2
 *
 *  Clock TIM2: 170 MHz / (Prescaler+1) = 170 MHz / 170 = 1 MHz
 *  → 1 tick = 1 µs  → diff [µs] tra due denti consecutivi
 *
 *  rpm  = 60 × 10⁶ / (diff_µs × NUM_DENTI)
 *  km/h = rpm_medio × CIRC_RUOTA_M × 60 / 1000
 * --------------------------------------------------------------------- */
#define NUM_DENTI      22.0f
#define CIRC_RUOTA_M    1.8f              /* circonferenza ruota [m]       */
#define IC_BUF_SIZE    16u

uint32_t          g_ic_buf_ch2[IC_BUF_SIZE];  /* DMA scrive TIM2 CH2 qui */
uint32_t          g_ic_buf_ch3[IC_BUF_SIZE];  /* DMA scrive TIM2 CH3 qui */
uint16_t          g_last_idx_ch2 = 0;
uint16_t          g_last_idx_ch3 = 0;
uint16_t          g_timeout_ch2  = 0;         /* cnt loop senza nuovi dati */
uint16_t          g_timeout_ch3  = 0;

volatile float    g_rpm1      = 0.0f;
volatile float    g_rpm2      = 0.0f;
volatile float    g_speed_kmh = 0.0f;

/* logging tick: globale per visibilità in debug */
uint32_t          g_log_tick  = 0;

/* USER CODE END PV */

void SystemClock_Config(void);
static void MX_GPIO_Init(void);
static void MX_DMA_Init(void);
static void MX_ADC1_Init(void);
static void MX_IWDG_Init(void);
static void MX_LPUART1_UART_Init(void);
static void MX_FDCAN1_Init(void);
static void MX_FDCAN2_Init(void);
static void MX_TIM2_Init(void);
/* USER CODE BEGIN 0 */

/* -----------------------------------------------------------------------
 *  Serial_Log – invia stringa formattata su LPUART1 via DMA
 *  Stesso pattern di Serial.c: buffer statico + flag busy + callback
 *  Il chiamante attende al più 20 ms che il TX precedente finisca;
 *  se scade il timeout il messaggio viene scartato (no blocco).
 * --------------------------------------------------------------------- */
void Serial_Log(const char *fmt, ...)
{
    uint32_t t0 = HAL_GetTick();
    while (g_lpuart_busy && (HAL_GetTick() - t0 < 20u)) {}
    if (g_lpuart_busy) return;

    va_list ap;
    va_start(ap, fmt);
    int len = vsnprintf(g_lpuart_buf, sizeof(g_lpuart_buf), fmt, ap);
    va_end(ap);

    if (len <= 0 || len >= (int)sizeof(g_lpuart_buf)) return;

    g_lpuart_busy = 1u;
    if (HAL_UART_Transmit_DMA(&hlpuart1, (uint8_t *)g_lpuart_buf, (uint16_t)len) != HAL_OK)
        g_lpuart_busy = 0u;
}

/* -----------------------------------------------------------------------
 *  HAL Callbacks
 * --------------------------------------------------------------------- */

/* TX LPUART completato → libera il flag (chiamato da DMA1_Ch1 IRQ) */
void HAL_UART_TxCpltCallback(UART_HandleTypeDef *huart)
{
    if (huart->Instance == LPUART1)
        g_lpuart_busy = 0u;
}

/* Pulsante B1 (PC13, rising edge EXTI) → schedula TX su CAN1 */
void HAL_GPIO_EXTI_Callback(uint16_t GPIO_Pin)
{
    if (GPIO_Pin == USER_BUTTON_Pin)
        g_btn_tx_req = 1u;
}

/*
 * FDCAN RX FIFO0 callback – svuota il FIFO in loop (gestisce burst)
 *  • CAN1: toggle LED verde (PA5) ad ogni frame ricevuto
 *  • CAN2: incrementa solo il contatore
 */
void HAL_FDCAN_RxFifo0Callback(FDCAN_HandleTypeDef *hfdcan, uint32_t RxFifo0ITs)
{
    if (!(RxFifo0ITs & FDCAN_IT_RX_FIFO0_NEW_MESSAGE)) return;

    while (HAL_FDCAN_GetRxFifoFillLevel(hfdcan, FDCAN_RX_FIFO0) > 0u)
    {
        HAL_FDCAN_GetRxMessage(hfdcan, FDCAN_RX_FIFO0, &g_can_rx_hdr, g_can_rx_data);

        if (hfdcan->Instance == FDCAN1)
        {
            g_can1_rx_cnt++;
            HAL_GPIO_TogglePin(USER_LED_GPIO_Port, USER_LED_Pin);
        }
        else if (hfdcan->Instance == FDCAN2)
        {
            g_can2_rx_cnt++;
        }
    }
}

/* USER CODE END 0 */

/**
  * @brief  The application entry point.
  * @retval int
  */
int main(void)
{

  /* MCU Configuration--------------------------------------------------------*/

  /* Reset of all peripherals, Initializes the Flash interface and the Systick. */
  HAL_Init();

  /* Configure the system clock */
  SystemClock_Config();

  /* Initialize all configured peripherals */
  MX_GPIO_Init();
  MX_DMA_Init();
  MX_ADC1_Init();
  MX_IWDG_Init();
  MX_LPUART1_UART_Init();
  MX_FDCAN1_Init();
  MX_FDCAN2_Init();
  MX_TIM2_Init();
  /* USER CODE BEGIN 2 */

  /* -----------------------------------------------------------------------
   *  ADC – calibrazione offset + avvio DMA continuo circolare
   * --------------------------------------------------------------------- */
  HAL_ADCEx_Calibration_Start(&hadc1, ADC_SINGLE_ENDED);
  HAL_ADC_Start_DMA(&hadc1, (uint32_t *)g_adc, ADC_NUM_CH);

  /* -----------------------------------------------------------------------
   *  FDCAN1 – filtro "accetta tutto" standard, start, notifica RX
   * --------------------------------------------------------------------- */
  {
    FDCAN_FilterTypeDef f = {0};
    f.IdType       = FDCAN_STANDARD_ID;
    f.FilterIndex  = 0;
    f.FilterType   = FDCAN_FILTER_MASK;
    f.FilterConfig = FDCAN_FILTER_TO_RXFIFO0;
    f.FilterID1    = 0x000u;
    f.FilterID2    = 0x000u;   /* maschera 0 → accetta qualunque ID standard */

    HAL_FDCAN_ConfigFilter(&hfdcan1, &f);
    HAL_FDCAN_ConfigGlobalFilter(&hfdcan1,
        FDCAN_ACCEPT_IN_RX_FIFO0, FDCAN_ACCEPT_IN_RX_FIFO0,
        FDCAN_REJECT, FDCAN_REJECT);
    if (HAL_FDCAN_Start(&hfdcan1) != HAL_OK) { Error_Handler(); }
    HAL_FDCAN_ActivateNotification(&hfdcan1, FDCAN_IT_RX_FIFO0_NEW_MESSAGE, 0);
  }

  /* -----------------------------------------------------------------------
   *  FDCAN2 – stesso schema
   * --------------------------------------------------------------------- */
  {
    FDCAN_FilterTypeDef f = {0};
    f.IdType       = FDCAN_STANDARD_ID;
    f.FilterIndex  = 0;
    f.FilterType   = FDCAN_FILTER_MASK;
    f.FilterConfig = FDCAN_FILTER_TO_RXFIFO0;
    f.FilterID1    = 0x000u;
    f.FilterID2    = 0x000u;

    HAL_FDCAN_ConfigFilter(&hfdcan2, &f);
    HAL_FDCAN_ConfigGlobalFilter(&hfdcan2,
        FDCAN_ACCEPT_IN_RX_FIFO0, FDCAN_ACCEPT_IN_RX_FIFO0,
        FDCAN_REJECT, FDCAN_REJECT);
    if (HAL_FDCAN_Start(&hfdcan2) != HAL_OK) { Error_Handler(); }
    HAL_FDCAN_ActivateNotification(&hfdcan2, FDCAN_IT_RX_FIFO0_NEW_MESSAGE, 0);
  }

  /* -----------------------------------------------------------------------
   *  TIM2 IC DMA – avvio circolare su CH2 (PB3) e CH3 (PB10)
   *  DMA già configurato in DMA_CIRCULAR nel MSP generato da CubeMX.
   * --------------------------------------------------------------------- */
  HAL_TIM_IC_Start_DMA(&htim2, TIM_CHANNEL_2, g_ic_buf_ch2, IC_BUF_SIZE);
  HAL_TIM_IC_Start_DMA(&htim2, TIM_CHANNEL_3, g_ic_buf_ch3, IC_BUF_SIZE);

  Serial_Log("=== Nucleo G474RE test start ===\r\n");

  /* USER CODE END 2 */

  /* Infinite loop */
  /* USER CODE BEGIN WHILE */
  while (1)
  {
    /* USER CODE END WHILE */

    /* USER CODE BEGIN 3 */

    uint32_t now = HAL_GetTick();

    /* ---------------------------------------------------------------
     *  Pulsante B1 → TX su CAN1 (ID 0x123, 8 byte)
     * ------------------------------------------------------------- */
    if (g_btn_tx_req)
    {
      g_btn_tx_req = 0u;

      FDCAN_TxHeaderTypeDef txh = {0};
      txh.Identifier          = 0x123u;
      txh.IdType              = FDCAN_STANDARD_ID;
      txh.TxFrameType         = FDCAN_DATA_FRAME;
      txh.DataLength          = FDCAN_DLC_BYTES_8;
      txh.ErrorStateIndicator = FDCAN_ESI_ACTIVE;
      txh.BitRateSwitch       = FDCAN_BRS_OFF;
      txh.FDFormat            = FDCAN_CLASSIC_CAN;
      txh.TxEventFifoControl  = FDCAN_NO_TX_EVENTS;
      txh.MessageMarker       = 0;

      uint8_t txd[8] = {0xDE, 0xAD, 0xBE, 0xEF, 0x01, 0x02, 0x03, 0x04};
      if (HAL_FDCAN_AddMessageToTxFifoQ(&hfdcan1, &txh, txd) == HAL_OK)
        Serial_Log("CAN1 TX ok\r\n");
      else
        Serial_Log("CAN1 TX ERR (bus assente?)\r\n");
    }

    /* ---------------------------------------------------------------
     *  Bus-off recovery – se il CAN è isolato, PSR.BO viene settato
     *  dopo che il TEC supera 256 (es. dopo 32 TX senza ACK).
     *  Stop + Start resetta i contatori di errore.
     * ------------------------------------------------------------- */
    if (hfdcan1.Instance->PSR & FDCAN_PSR_BO)
    {
      HAL_FDCAN_Stop(&hfdcan1);
      HAL_FDCAN_Start(&hfdcan1);
      Serial_Log("FDCAN1 bus-off: recovery\r\n");
    }
    if (hfdcan2.Instance->PSR & FDCAN_PSR_BO)
    {
      HAL_FDCAN_Stop(&hfdcan2);
      HAL_FDCAN_Start(&hfdcan2);
      Serial_Log("FDCAN2 bus-off: recovery\r\n");
    }

    /* ---------------------------------------------------------------
     *  RUOTA 1 – TIM2 CH2 (PB3)
     *
     *  NDTR del DMA conta quante scritture mancano a riempire il buffer.
     *  curr_idx = posizione corrente di scrittura nel buffer circolare.
     *  Il % IC_BUF_SIZE gestisce il caso NDTR==0 (wrap-around DMA).
     * ------------------------------------------------------------- */
    {
      uint16_t ndtr     = (uint16_t)__HAL_DMA_GET_COUNTER(htim2.hdma[TIM_DMA_ID_CC2]);
      uint16_t curr_idx = (uint16_t)((IC_BUF_SIZE - ndtr) % IC_BUF_SIZE);

      if (curr_idx != g_last_idx_ch2)
      {
        /* ultimi due timestamp catturati in ordine circolare */
        uint16_t i_new  = (uint16_t)((curr_idx - 1u + IC_BUF_SIZE) % IC_BUF_SIZE);
        uint16_t i_prev = (uint16_t)((curr_idx - 2u + IC_BUF_SIZE) % IC_BUF_SIZE);

        /* sottrazione uint32 gestisce overflow del counter a 32 bit */
        uint32_t diff = g_ic_buf_ch2[i_new] - g_ic_buf_ch2[i_prev];
        if (diff > 0u)
          g_rpm1 = 60000000.0f / ((float)diff * NUM_DENTI);

        g_last_idx_ch2 = curr_idx;
        g_timeout_ch2  = 0u;
      }
      else
      {
        if (g_timeout_ch2 < 0xFFFFu) g_timeout_ch2++;
        if (g_timeout_ch2 > 10u) g_rpm1 = 0.0f;   /* ~100 ms → ruota ferma */
      }
    }

    /* ---------------------------------------------------------------
     *  RUOTA 2 – TIM2 CH3 (PB10)
     * ------------------------------------------------------------- */
    {
      uint16_t ndtr     = (uint16_t)__HAL_DMA_GET_COUNTER(htim2.hdma[TIM_DMA_ID_CC3]);
      uint16_t curr_idx = (uint16_t)((IC_BUF_SIZE - ndtr) % IC_BUF_SIZE);

      if (curr_idx != g_last_idx_ch3)
      {
        uint16_t i_new  = (uint16_t)((curr_idx - 1u + IC_BUF_SIZE) % IC_BUF_SIZE);
        uint16_t i_prev = (uint16_t)((curr_idx - 2u + IC_BUF_SIZE) % IC_BUF_SIZE);

        uint32_t diff = g_ic_buf_ch3[i_new] - g_ic_buf_ch3[i_prev];
        if (diff > 0u)
          g_rpm2 = 60000000.0f / ((float)diff * NUM_DENTI);

        g_last_idx_ch3 = curr_idx;
        g_timeout_ch3  = 0u;
      }
      else
      {
        if (g_timeout_ch3 < 0xFFFFu) g_timeout_ch3++;
        if (g_timeout_ch3 > 10u) g_rpm2 = 0.0f;
      }
    }

    /* ---------------------------------------------------------------
     *  Velocità veicolo
     *  km/h = rpm_medio × circ[m] × 60 / 1000
     * ------------------------------------------------------------- */
    g_speed_kmh = ((g_rpm1 + g_rpm2) * 0.5f * CIRC_RUOTA_M * 60.0f) / 1000.0f;

    /* ---------------------------------------------------------------
     *  Log UART ogni 200 ms
     *  ADC raw 12-bit, RPM ruote, velocità, contatori CAN RX
     * ------------------------------------------------------------- */
    if (now - g_log_tick >= 200u)
    {
      g_log_tick = now;
      Serial_Log("ADC[%4d,%4d,%4d,%4d] RPM1=%6.1f RPM2=%6.1f V=%5.1f km/h RX1=%u RX2=%u\r\n",
                 (int)g_adc[0], (int)g_adc[1], (int)g_adc[2], (int)g_adc[3],
                 (double)g_rpm1, (double)g_rpm2, (double)g_speed_kmh,
                 (unsigned int)g_can1_rx_cnt, (unsigned int)g_can2_rx_cnt);
    }

    /* kick watchdog (timeout IWDG ≈ 1 s) */
    HAL_IWDG_Refresh(&hiwdg);

    HAL_Delay(10);
  }
  /* USER CODE END 3 */
}

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


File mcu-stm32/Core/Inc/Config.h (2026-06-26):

/**
 * @file Config.h
 * @author Alessandro Zingaretti | Polimarche Racing Team - UNIVPM
 * @brief Global configuration and build options
 * 
 * This file contains compile-time configuration switches for
 * different build modes (test, debug, release).
 * 
 */

#ifndef CONFIG_H
#define CONFIG_H

#ifdef __cplusplus
extern "C" {
#endif


/* =========================================================
 * Serial logging enable/disable
 *
 * Comment out a define to completely silence that UART channel.
 * The corresponding Serial4_Log / Serial3_Log calls compile to
 * a single (void)format statement — no code generated, no CPU cost.
 * ========================================================= */
#define SERIAL4_LOG_ENABLED   /**< UART4 — ESP32 bridge */
#define SERIAL3_LOG_ENABLED   /**< UART3 — PC via STLink VCOM */


#define R2D_BYPASS   /**< Comment out to require real R2D from CAN2 */


/* =========================================================
 * DATA COLLECTION MODE
 *
 * When defined, data_logger outputs a SINGLE CSV line on
 * UART4 only (no verbose text). Designed for bench logging
 * through ESP32 → WiFi → Python script.
 *
 * FEATHER_LOCAL — MCU invia 20 campi, Feather appende NTC1/2/3 → 23 colonne totali:
 *   Time_ms, TempMotor, TempInverter, TempIGBT, Voltage, Speed,
 *   Iq, Id, TorqueMotor, PedalPerc,
 *   InvState, ErrCode, StatusWord, ErrInfo1,
 *   PhaseU_mA, PhaseV_mA, PhaseW_mA, Power_W,
 *   TorqueSetpoint, TorqueLimitDyn,
 *   NTC1, NTC2, NTC3
 *
 * ESP32_REMOTE — MCU invia 20 campi, ESP32 appende NTC1/2/3 → 23 colonne totali:
 *   Time_ms, TempMotor, TempInverter, TempIGBT, Voltage, Speed,
 *   Iq, Id, TorqueMotor, PedalPerc, InvState, ErrCode, StatusWord, ErrInfo1,
 *   PhaseU_mA, PhaseV_mA, PhaseW_mA, Power_W, TorqueSetpoint, TorqueLimitDyn,
 *   NTC1, NTC2, NTC3
 *
 * UART4 baud rate: 9600 (corrisponde a UART_BAUD nel firmware Feather e SERIAL2_BAUD nell'ESP32)
 * ========================================================= */
#define DATA_COLLECT_MODE

/** Sampling period [ms] when DATA_COLLECT_MODE is active */
#define DATA_COLLECT_PERIOD_MS      100U

/* Data collection backend selection:
 * - ESP32_REMOTE  : STM32 keeps normal CSV/debug stream over UART4
 * - FEATHER_LOCAL : STM32 drives Feather logging protocol ([START]/[STOP])
 */
#define DATA_COLLECT_BACKEND_ESP32_REMOTE   1U
#define DATA_COLLECT_BACKEND_FEATHER_LOCAL  2U
#define DATA_COLLECT_BACKEND                DATA_COLLECT_BACKEND_FEATHER_LOCAL

#if ((DATA_COLLECT_BACKEND != DATA_COLLECT_BACKEND_ESP32_REMOTE) && \
     (DATA_COLLECT_BACKEND != DATA_COLLECT_BACKEND_FEATHER_LOCAL))
    #error "Invalid DATA_COLLECT_BACKEND value"
#endif


/*==========================================================================================================================================*/
/*==========================================================================================================================================*/
/*==========================================================================================================================================*/
/*==========================================================================================================================================*/
/*==========================================================================================================================================*/
/*==========================================================================================================================================*/
/*==========================================================================================================================================*/



#define APPS_NUM_SENSORS            1U

/* ============================================================================
 * BUILD MODE CONFIGURATION
 * ============================================================================
 * Uncomment ONE of the following to select the build mode:
 * 
 * - RELEASE_MODE:         Release/race mode - FULL SAFETY ACTIVE
 *                         - 3 complete ADC channels (APPS1, APPS2, STEERING)
 *                         - Plausibility check APPS1 vs APPS2 active
 *                         - Range check sensors active
 *                         - Deadzone 30% active    
 *                         - Timeout implausibility active
 *                         - Requires complete hardware and accurate calibration!
 * 
 * - TEST_MODE_SINGLE_ADC: Only ADC1 CH0 (PA0) is available for testing.
 *                         APPS uses only sensor 1, plausibility checks disabled.
 * 
 * - TEST_MODE_FULL:       All ADC channels available, but plausibility
 *                         checks are more lenient for bench testing.
 * 
 * ============================================================================ */
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

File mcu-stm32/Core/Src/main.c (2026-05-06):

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
/* Includes ------------------------------------------------------------------*/
#include "main.h"
#include "cmsis_os.h"

/* USER CODE BEGIN Includes */
#include "Config.h"
#include "Safety/watchdog.h"
#include "FreeRTOS.h"
#include "Can.h"
#include "Serial.h"
#include "Drive/Inverter.h"
#include "Sensors/ADC_Manager.h"
#include "Tasks/data_logger.h"
#include "Tasks/motors_manager.h"
#include "Tasks/data_manager.h"
#include "Safety/device_state.h"
#include "task.h"
/* USER CODE END Includes */

ADC_HandleTypeDef hadc1;
DMA_HandleTypeDef hdma_adc1;

CAN_HandleTypeDef hcan1;
CAN_HandleTypeDef hcan2;

IWDG_HandleTypeDef hiwdg;

UART_HandleTypeDef huart4;
UART_HandleTypeDef huart3;
DMA_HandleTypeDef hdma_uart4_tx;
DMA_HandleTypeDef hdma_usart3_tx;

/* Definitions for DataLogger */
osThreadId_t DataLoggerHandle;
const osThreadAttr_t DataLogger_attributes = {
  .name = "DataLogger",
  .stack_size = 1024 * 4,
  .priority = (osPriority_t) osPriorityLow,
};
/* Definitions for MotorsManager */
osThreadId_t MotorsManagerHandle;
const osThreadAttr_t MotorsManager_attributes = {
  .name = "MotorsManager",
  .stack_size = 2048 * 4,
  .priority = (osPriority_t) osPriorityAboveNormal,
};
/* Definitions for DataManager */
osThreadId_t DataManagerHandle;
const osThreadAttr_t DataManager_attributes = {
  .name = "DataManager",
  .stack_size = 512 * 4,
  .priority = (osPriority_t) osPriorityHigh,
};
/* Definitions for mutex_APPS */
osMutexId_t mutex_APPSHandle;
const osMutexAttr_t mutex_APPS_attributes = {
  .name = "mutex_APPS"
};
/* Definitions for mutex_SAS */
osMutexId_t mutex_SASHandle;
const osMutexAttr_t mutex_SAS_attributes = {
  .name = "mutex_SAS"
};
/* Definitions for mutex_INVERTER_L */
osMutexId_t mutex_INVERTER_LHandle;
const osMutexAttr_t mutex_INVERTER_L_attributes = {
  .name = "mutex_INVERTER_L"
};
/* Definitions for mutex_INVERTER_R */
osMutexId_t mutex_INVERTER_RHandle;
const osMutexAttr_t mutex_INVERTER_R_attributes = {
  .name = "mutex_INVERTER_R"
};
/* Definitions for mutex_CAN1 */
osMutexId_t mutex_CAN1Handle;
const osMutexAttr_t mutex_CAN1_attributes = {
  .name = "mutex_CAN1"
};
/* Definitions for mutex_UART3 */
osMutexId_t mutex_UART3Handle;
const osMutexAttr_t mutex_UART3_attributes = {
  .name = "mutex_UART3"
};
/* Definitions for mutex_CAN2 */
osMutexId_t mutex_CAN2Handle;
const osMutexAttr_t mutex_CAN2_attributes = {
  .name = "mutex_CAN2"
};
/* Definitions for mutex_UART4 */
osMutexId_t mutex_UART4Handle;
const osMutexAttr_t mutex_UART4_attributes = {
  .name = "mutex_UART4"
};
void SystemClock_Config(void);
static void MX_GPIO_Init(void);
static void MX_DMA_Init(void);
static void MX_CAN1_Init(void);
static void MX_ADC1_Init(void);
static void MX_USART3_UART_Init(void);
static void MX_CAN2_Init(void);
static void MX_IWDG_Init(void);
static void MX_UART4_Init(void);
void StartDataLogger(void *argument);
void StartMotorsManager(void *argument);
void StartDataManager(void *argument);

/* USER CODE BEGIN PFP */
void MX_FREERTOS_Init(void);

/* USER CODE END PFP */

/**
  * @brief  The application entry point.
  * @retval int
  */
int main(void)
{

  /* MCU Configuration--------------------------------------------------------*/

  /* Reset of all peripherals, Initializes the Flash interface and the Systick. */
  HAL_Init();

  /* Configure the system clock */
  SystemClock_Config();

  /* Initialize all configured peripherals */
  MX_GPIO_Init();
  MX_DMA_Init();
  MX_CAN1_Init();
  MX_ADC1_Init();
  MX_USART3_UART_Init();
  MX_CAN2_Init();
  MX_IWDG_Init();
  MX_UART4_Init();
  /* USER CODE BEGIN 2 */

  DeviceState_Set(DEVICE_STATE_INIT);
  
  /* Freeze Independent Watchdog (IWDG) while debugging:
   * When the debugger halts the CPU, the IWDG would normally continue
   * counting and eventually reset the MCU. Calling this macro freezes
   * the IWDG counter while the core is halted by the debugger. It has
   * no effect when no debugger is connected.
   */
  __HAL_DBGMCU_FREEZE_IWDG();

  /* Ensure the IWDG counter is refreshed immediately after initialization
   * to give the rest of the system time to complete startup without
   * triggering an unwanted reset. This is a one-time refresh; periodic
   * refreshes are handled by the safety monitor task.
   */
  Watchdog_Refresh();

  Inverters_Init();
  DataReadings_Init();
  Watchdog_Refresh();
  //SchedulerInitFct();
  /* USER CODE END 2 */

  /* Init scheduler */
  osKernelInitialize();
  /* Create the mutex(es) */
  /* creation of mutex_APPS */
  mutex_APPSHandle = osMutexNew(&mutex_APPS_attributes);

  /* creation of mutex_SAS */
  mutex_SASHandle = osMutexNew(&mutex_SAS_attributes);

  /* creation of mutex_INVERTER_L */
  mutex_INVERTER_LHandle = osMutexNew(&mutex_INVERTER_L_attributes);

  /* creation of mutex_INVERTER_R */
  mutex_INVERTER_RHandle = osMutexNew(&mutex_INVERTER_R_attributes);

  /* creation of mutex_CAN1 */
  mutex_CAN1Handle = osMutexNew(&mutex_CAN1_attributes);

  /* creation of mutex_UART3 */
  mutex_UART3Handle = osMutexNew(&mutex_UART3_attributes);

  /* creation of mutex_CAN2 */
  mutex_CAN2Handle = osMutexNew(&mutex_CAN2_attributes);

  /* creation of mutex_UART4 */
  mutex_UART4Handle = osMutexNew(&mutex_UART4_attributes);

  /* USER CODE BEGIN RTOS_MUTEX */
  /* add mutexes, ... */
  /* USER CODE END RTOS_MUTEX */

  /* USER CODE BEGIN RTOS_SEMAPHORES */
  /* add semaphores, ... */
  /* USER CODE END RTOS_SEMAPHORES */

  /* USER CODE BEGIN RTOS_TIMERS */
  /* start timers, add new ones, ... */
  /* USER CODE END RTOS_TIMERS */

  /* USER CODE BEGIN RTOS_QUEUES */
  /* CAN RX queues must be created after osKernelInitialize() and before CAN IRQ notifications. */
  CAN_ProcessQueue_Init();      /* CAN1 RX queue */
  CAN_Car_ProcessQueue_Init();  /* CAN2 RX queue */

  if (!CAN_QueuesReady())
  {
    Error_Handler();
  }

  /* Defer CAN peripheral start to task context (after osKernelStart). */
  /* USER CODE END RTOS_QUEUES */

  /* Create the thread(s) */
  /* creation of DataLogger */
  DataLoggerHandle = osThreadNew(StartDataLogger, NULL, &DataLogger_attributes);

  /* creation of MotorsManager */
  MotorsManagerHandle = osThreadNew(StartMotorsManager, NULL, &MotorsManager_attributes);

  /* creation of DataManager */
  DataManagerHandle = osThreadNew(StartDataManager, NULL, &DataManager_attributes);

  /* USER CODE BEGIN RTOS_THREADS */
  /* add threads, ... */
  /* USER CODE END RTOS_THREADS */

  /* USER CODE BEGIN RTOS_EVENTS */
  /* add events, ... */
  /* USER CODE END RTOS_EVENTS */

  /* Start scheduler */
  osKernelStart();

  /* We should never get here as control is now taken by the scheduler */

  /* Infinite loop */
  /* USER CODE BEGIN WHILE */
  while (1)
  {
	  //SchedulerMgmFct();
    /* USER CODE END WHILE */

    /* USER CODE BEGIN 3 */
  }
  /* USER CODE END 3 */
}
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

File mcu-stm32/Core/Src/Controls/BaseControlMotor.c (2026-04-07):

/**
 * @file BaseControlMotor.c
 * @author Alessandro Zingaretti | Polimarche Racing Team - UNIVPM
 * @brief Implementation of basic engine & Inverter control functions
 */

#include "Controls/BaseControlMotor.h"
#include "Communication/Can.h"
#include "Communication/Serial.h"
#include "APP/APPS.h"
#include "Config.h"
#include <math.h>
#include <stdlib.h>
#include <string.h>

#if defined(DATA_COLLECT_MODE) && (DATA_COLLECT_BACKEND == DATA_COLLECT_BACKEND_FEATHER_LOCAL)
    #define MOTOR_ERR_LOG_CHANNEL  LOG_CH_UART3
#else
    #define MOTOR_ERR_LOG_CHANNEL  LOG_CH_BOTH
#endif

/* CAN transmission diagnostics (global variables) */
uint32_t g_can_tx_ok_count = 0;
uint32_t g_can_tx_fail_count = 0;

/* CAN reception diagnostics */
uint32_t g_can_rx_count = 0;  // Messages received from inverter

#ifndef M_PI
#define M_PI 3.14159265358979323846f
#endif

volatile int16_t torque_request;    /**< Written by InvertersManageTask, read by DataLoggerTask — must be volatile */
volatile int16_t torque_limit_dyn;  /**< Written by InvertersManageTask, read by DataLoggerTask — must be volatile */

#if defined(REGEN_ENABLED) && REGEN_ENABLED
/* Latch regen selection per node_id to avoid mode chattering near pedal threshold. */
static bool s_regen_latch[3] = {false, false, false};

static bool Motor_ShouldUseRegen(const Inverter_t *inv, uint8_t pedal_percent)
{
    if (inv == NULL || inv->node_id == 0U || inv->node_id >= 3U) {
        return false;
    }

    if (inv->state != INV_STATE_RUNNING) {
        s_regen_latch[inv->node_id] = false;
        return false;
    }

    /* Speed hysteresis on latch RESET:
     *   - Latch CAN DEACTIVATE only when speed drops below REGEN_SPEED_CRITICAL_RPM
     *     (already the intended exit threshold).
     *   - We do NOT reset the latch here if speed flickers
     *     around CRITICAL. The latch reset due to speed happens only when
     *     speed is strictly below CRITICAL — the lower-guard prevents
     *     re-triggering from noise.
     * The check below uses a 10% lower guard band so noise around 2000 RPM
     * does NOT cause repeated latch-reset -> regen-enter oscillations. */
    const int16_t speed_latch_reset_thr = (int16_t)(REGEN_SPEED_CRITICAL_RPM * 9U / 10U); /* 90% of CRITICAL = 1800 RPM */
    if (inv->speed_rpm <= speed_latch_reset_thr) {
        s_regen_latch[inv->node_id] = false;
        return false;
    }

    /* If latch is ON but speed fell below CRITICAL (but above the hard reset above),
     * keep the latch alive but let k_vel fade-out smooth the torque to ~0. */
    if (!s_regen_latch[inv->node_id] && inv->speed_rpm <= (int16_t)REGEN_SPEED_CRITICAL_RPM) {
        /* Speed is in [speed_latch_reset_thr, CRITICAL]: cannot enter regen */
        return false;
    }

    const uint8_t threshold = REGEN_PEDAL_THRESHOLD_PCT;
    const uint8_t hysteresis = REGEN_PEDAL_HYST_PCT;
    const uint8_t enter_thr = (threshold > hysteresis) ? (threshold - hysteresis) : 0U;
    const uint8_t exit_thr = ((uint16_t)threshold + (uint16_t)hysteresis <= 100U)
        ? (uint8_t)(threshold + hysteresis)
        : 100U;

    if (s_regen_latch[inv->node_id]) {
        if (pedal_percent >= exit_thr) {
            s_regen_latch[inv->node_id] = false;
        }
    } else {
        /* Enter regen only if pedal is low AND speed is high enough.
         * This creates speed hysteresis: enter at SPEED_MIN,
         * exit at SPEED_CRITICAL — avoids entering regen at
         * marginal speeds where k_vel fade-out makes it near-zero. */
        if (pedal_percent <= enter_thr && inv->speed_rpm > (int16_t)REGEN_SPEED_MIN_RPM) {
            s_regen_latch[inv->node_id] = true;
        }
    }

    return s_regen_latch[inv->node_id];
}
#endif

extern uint32_t s_error_l_timestamp;
extern uint16_t s_error_l_dc_voltage;
extern int16_t  s_error_l_torque;
extern int16_t  s_error_l_speed;
extern uint32_t s_error_r_timestamp;
extern uint16_t s_error_r_dc_voltage;
extern int16_t  s_error_r_torque;
extern int16_t  s_error_r_speed;

int16_t Motor_CalculateDynamicTorqueLimit(int16_t speed_rpm, uint32_t actual_power) {
    float speed = (float)abs(speed_rpm);
    
    if (speed < 10.0f) speed = 10.0f;
    
    /* Calculate available power: P = V × I × η */
    float power_w = actual_power * MOTOR_EFFICIENCY;  /* Account for estimated efficiency losses */
    
    /* AMK formula: M_soll_max = P / (2 × π × N_ist / 60) */
    float omega_rad_s = 2.0f * M_PI * speed / 60.0f;
    float torque_lim_nm = power_w / omega_rad_s;
    
    /* Saturation to motor mechanical limit */
    if (torque_lim_nm > MOTOR_MAX_TORQUE_NM) {
        torque_lim_nm = MOTOR_MAX_TORQUE_NM;
    }
    
    /* Conversion to CAN units */
    return (int16_t)((torque_lim_nm / MOTOR_NOMINAL_TORQUE_NM) * CAN1_SCALE_FACTOR);
}


int16_t Motor_ApplyTorqueRateLimit(int16_t target, int16_t previous, int16_t max_delta) {
    int16_t delta = target - previous;
    
    if (delta > max_delta) {
        return previous + max_delta;
    } else if (delta < -max_delta) {
        return previous - max_delta;
    } else {
        return target;
    }
}


#ifdef REGEN_ENABLED
#if REGEN_ENABLED
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

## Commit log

2026-03-21 Repo Init
    [FreeCanConfiguration_Speed_Setpoint_2021-24_en.xlsx, FreeCanConfiguration_Torque_Setpoint_2021-24_en.xlsx, Parameter Selection - Own List V01.txt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]
2026-03-23 Starting to work on TorqueVectoringControl and adjustments on DataCollectorSoftware
    [dati_sensori_20260323_161948.csv, dati_sensori_20260323_162007.csv, dati_sensori_20260323_162035.csv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]
2026-03-23 Add Steer2Wheel.c utils tool in C and TV control updates
2026-03-29 Creaated new DataCollector firmware for a Feather M4 Can Express, Created a python software for the comuncation with the feather datas collector, updated Throttle pedal behaviour and AIPEX Inverter 1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
    [DD5-4-10-xOO.stp, DD7-43-12-xBO.stp, DD7-50-10-xBO.stp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]
2026-03-30 Disable left inverter and add CAN error logging
    Configure project for a single right-side inverter: set INVERTER_LEFT_PRESENT=0 and disable REGEN in Config.h, and update example comments. Make inverter init/register conditional on presence and prevent CAN commands being sent to absent nodes. Improve CAN robustness by including Config.h, enabling error notifications, adding HAL_CAN_ErrorCallback to log ESR/TEC/REC, and restoring the FIFO processing loop.
    [Config.h, Inverter.c]
2026-04-02 Worked on Torque Vectoring Controller and Creater a 3D render for simulations
    Started to put real datas in the 3DOF Vehicle Block
2026-04-05 Add CAN/torque docs, update STM32 MCU tasks & CAN, Probably Fixed Regen's Errors
    Update MCU firmware sources and headers to improve CAN handling, inverter logic, serial comms, mutexes and task management (multiple changes under mcu-stm32/Core: Communication, Inverter, Controls, Tasks, main, mutexes and .ioc). Also replace/update AIPEX project. These changes add protocol docs and bring firmware changes for CAN messaging, inverter control and data logging.
    [log_001.csv, log_004.csv]
2026-04-07 Introduced many versions of SLC (1 by PID, 2 "logical")
2026-04-07 Fixed CAN1 crash at boot. Renamed tasks and various minor updates.
    [BaseControlMotor.c, Can.h, Inverter.h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]
2026-04-07 Refactor ESP32 bridge & little fix to Feather firmware
2026-04-07 Refactored Sensors and Drive dirs, added MCU state machine
    Rename sensor and drive modules (APP/ADC/SAS -> Sensors, Controls/Inverter -> Drive.. Add new MCU_State safety module (MCU_State.h/.c) implementing top-level MCU state machine and integrate it into d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
2026-04-12 Uploaded Some logs from Test bench / Esp32 logs
2026-04-12 Updated MCU project's architecture: separated Regen and ErrorRecovery logics from BaseControlMotor, Implemented 2 AUTOTEST (to be tested), changed UART5/6 clock (SYSCLK now) and UART baudRate set to 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
    (still some issue with regen)
    [APPS.h, BaseControlMotor.c, BaseControlMotor.h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]
2026-04-22 Updated SLC and new PI values set
    [SLC1.obj, ert_main.obj, rt_nonfinite.obj]
2026-04-27 Created peackockElettricaSimulink.slx to virtualize the car on simulink + StateFlowChart
    Added the "derating" of the AMK's motor
    Updated SLC's PID value
    Updated TV Logic
    Included all Controller and their new version on an stand-alone file
2026-04-27 Fixed Air Temp (from 30 to 300K), new TVC pid values and repaired its logic
2026-04-27 Created new MCU'test project based on stm32 NUCLEO-g474re (test about peripheras for pcb)
2026-04-28 Changed Bicycle Model to Dynamic, added Yaw_th generator blockset and new conditions for states switch
2026-05-02 Updated AIPEX's files
    [Inverter104_RR.xls, Inverter204_RL_sw.xls]
2026-05-02 Updated Derating's simulation, added Blending switch (SLC-TVC), exported in C code DriveController (new file's setting allow the code generation). PID tuned
    [SLC1.obj, ert_main.obj, rt_nonfinite.obj]
2026-05-02 Updated Tests for DataCollector software
    [dati_sensori_20260429_130353.csv, dati_sensori_20260429_130824.csv, dati_sensori_20260429_130953.csv]
2026-05-02 Build of the stm32-g474re test project
2026-05-03 Uploaded Imu's docs
2026-05-06 Started to collect Data while Testing Motor's configurations
2026-05-06 Working and uploaded Tire's Data (next is to set wheels)
    [Log File_2026_4_10_12_18_29.csv, Log File_2026_4_10_12_40_39.csv, Log File_2026_4_10_12_48_1.csv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]
2026-05-06 Uploaded H755zi stm32 project made for testing phonic wheel signal (simulation by GPIO)
2026-05-06 Completed tests for the peripherals for the new mcu-board
2026-05-06 Regenerative Braking is working! Next: calibrate it
2026-05-07 Corrected SlipRatioController and fixed TireSetup issue (algebric loop)
    [sm_car_database_Vehicle.xlsx, sm_car_results.xlsx]
2026-05-08 Removed some Test passed projects
    [telemetria_esportata.csv, telemetry.xlsx]
2026-05-08 Logs of 08-05-2026
    Regen Tests, One full lap simulated (Valencia Kart track) and free running on different Voltages
    [dati_sensori_20260505_174253_clean.csv, dati_sensori_20260506_121000.csv, dati_sensori_20260506_121158.csv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]
2026-05-11 Enhance esp32_log_merger processing
    Improve robustness and usability of esp32_log_merger.py
    [dati_sensori_20260508_115650_clean.csv, dati_sensori_20260508_120922_350_16000_clean.csv, dati_sensori_20260508_122037_350_18000_clean.csv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]
2026-05-11 Updated SRC value's and found out Tires Slip Limit (Fz | 18Nm from engine)
2026-05-14 Adjust data collection, inverter, and torque limits. Unified AIPEX file for Inverters 104 & 204
2026-05-17 Add DataCollectorSoftware test logs and CSVs
    [dati_sensori_20260512_132139.csv, dati_sensori_20260512_132300.csv, dati_sensori_20260512_132450.csv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]
2026-05-19 Replaced SLC to MTFC, fixed GripEstimator, SRC to realistic response and TVC logic + yaw'slogic to real IMU system reference
2026-05-24 Updated SlipControl + new Maps for Acceleration Event tested for riduttore efficiency of 98%
    Generated Test Code From simulink and Embedded Coder
    [driveController.obj, driveController_data.obj, ert_main.obj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]
2026-05-24 Moved lap_data_simulations files
    [telemetria_esportata.csv, telemetry.xlsx]
2026-06-26 Uploaded changes to DataCollectorSoftware and local logs
    [dati_sensori_20260505_172027.csv, dati_sensori_20260505_172027_clean.csv, dati_sensori_20260505_174253.csv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]
2026-06-26 Sync with current files on local
2026-07-29 Controls: Backup. Implemented Powertrain Dynamic Limitations, first attempt to switch to "External Force" for 3DOF Body simulation without algebraic loops error
    First script for virtual tracks layout for path follower
    [velocityDistribution.xlsx]
2026-08-01 Generated DriverController Code with Embedded Coder and Removed TR Mode on TVC PID
    [driveController.obj, driveController_data.obj, ert_main.obj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]
2026-08-03 Updated DriveController Logic, SRC is before TVC control, Fixed CAR Plant, Update vehicle params and add tire data/model
2026-08-16 Path Follower and implemented different virtual tracks: 2 Endurance Tracks, Skidpad and acceleration
    [cones_left.stl, cones_right.stl]
2026-10-11 Uploaded Flowchart, renders, and architecture's illustration
2026-10-11 Created the new project for the MCU (VCU) for stm32 G474re

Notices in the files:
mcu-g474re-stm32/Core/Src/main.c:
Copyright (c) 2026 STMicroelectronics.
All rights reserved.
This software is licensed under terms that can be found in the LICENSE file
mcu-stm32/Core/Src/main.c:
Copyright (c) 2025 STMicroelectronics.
